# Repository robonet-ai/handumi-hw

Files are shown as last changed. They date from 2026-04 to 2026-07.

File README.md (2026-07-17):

# HandUMI - Hardware

<p align="center">
  
  
  
</p>

<p align="center">
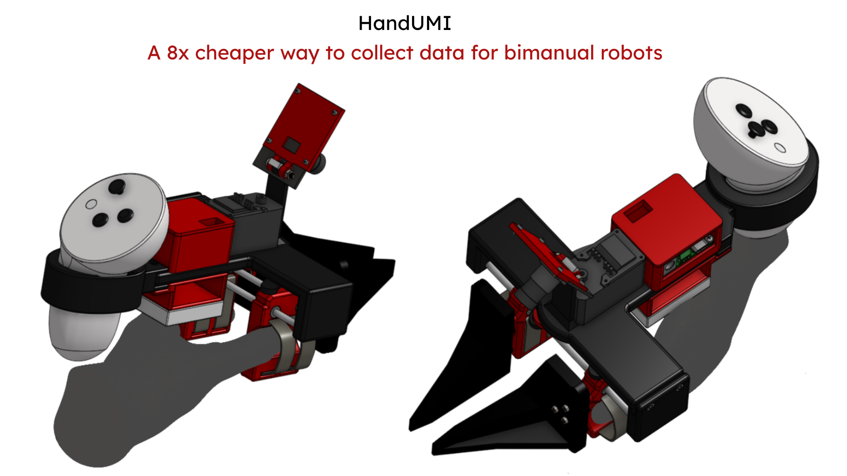
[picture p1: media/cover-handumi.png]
HandUMI - An 8x cheaper way to collect data for bimanual robots
  
</p>

A hand-worn, open-source variant of the Universal Manipulation Interface (UMI)
for collecting bimanual manipulation data without a robot in the loop, designed
for robot arms with parallel grippers. HandUMI mounts on the operator's thumb
and index/middle fingers, opens and closes with a natural pinch, and uses
interchangeable gripper tips to target different parallel-jaw robot grippers.
One unit costs roughly $110 in parts, plus the VR headset of the user's
preference (PICO 4 Ultra or Meta Quest 3).

HandUMI demonstrations are robot-agnostic: collect the data once with the
wearable hardware, then use the [HandUMI software](https://github.com/robonet-ai/handumi-sw)
to retarget it across different bimanual arms with parallel grippers.

## Why Teleoperation Is Not Scalable?

Traditional leader-follower teleoperation is expensive and lab-constrained.

It is expensive because collecting data for bimanual arms requires at least
four robotic arms: two follower arms plus two leader arms, or a VR
headset acting as the leader for both. Even low-cost leader arms like
[GELLO](https://wuphilipp.github.io/gello_site/), which replicate the
follower's kinematics in 3D-printed hardware to cut the leader cost to a few
hundred dollars each, still leave you duplicating both follower arms for
every operator who wants to collect data.

It is lab-constrained because the follower arm has to physically move to
wherever the data needs to be collected. Bolting an arm to a cart and hauling
it between rooms, buildings, or the environments you actually want to collect
data in is slow, heavy, and hard to scale beyond a single fixed setup.

I felt this pain firsthand: the NONHUMAN team and I collected over 2,000
episodes using this method
([link](https://huggingface.co/spaces/lerobot/visualize_dataset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)).

<p align="center">
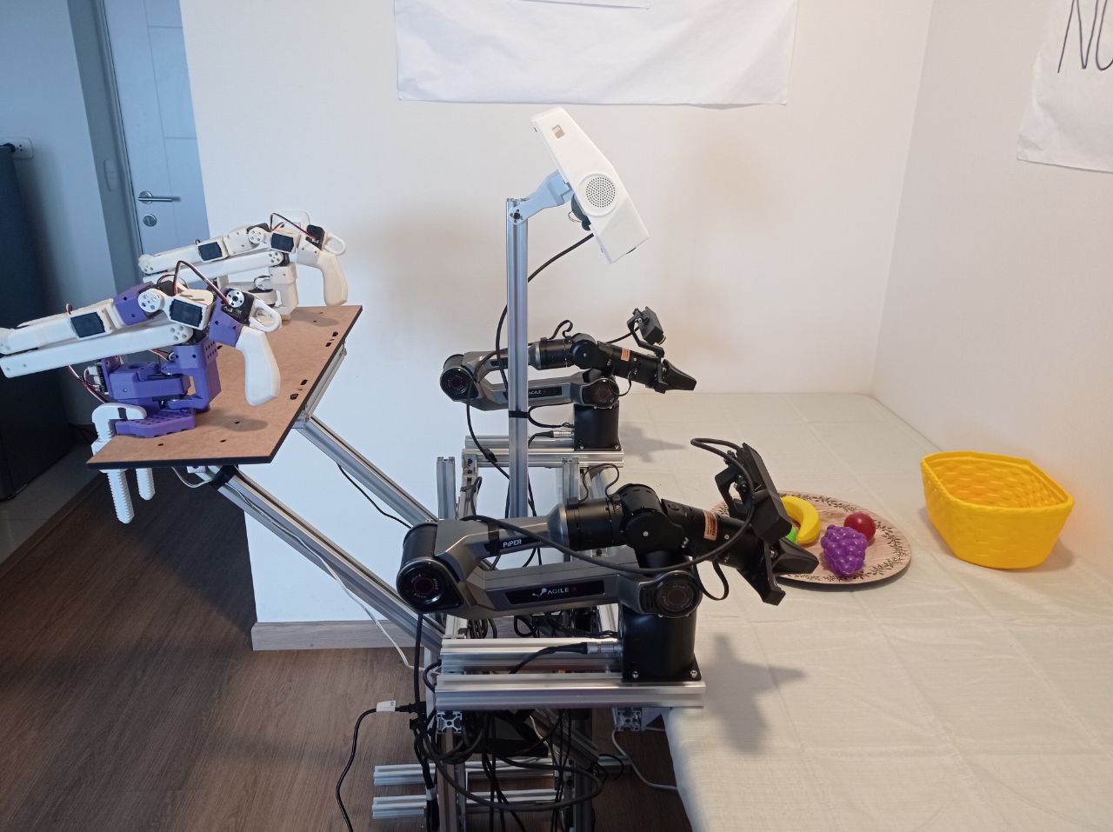
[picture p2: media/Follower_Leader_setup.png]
Classical bimanual leader-follower teleoperation setup
  
</p>

## Why HandUMI

HandUMI removes both the cost and the lab constraint by moving the collection
interface onto the operator's hand instead of onto a robot, the same way the
original UMI removed the lab constraint for its own gripper. This time, that
wearable concept is adapted from [Generalist](https://generalistai.com/)'s
approach and re-targeted at robot arms with parallel-jaw grippers, and it is
open-source and modular: the body, camera mount, servo, and tracker mounting
stay the same across robots, and only the detachable gripper tip changes to
target a new one. Demonstrations can then be captured directly from human
motion, anywhere, without a robot arm at all. Current target tips are AgileX
Piper, ARX X5 2023, Dream Gripper (TRLC), Trossen WidowX AI, and the original
UMI gripper.

Any robot with a comparable parallel-jaw gripper can be supported by designing
and printing a matching tip.

<p align="center">
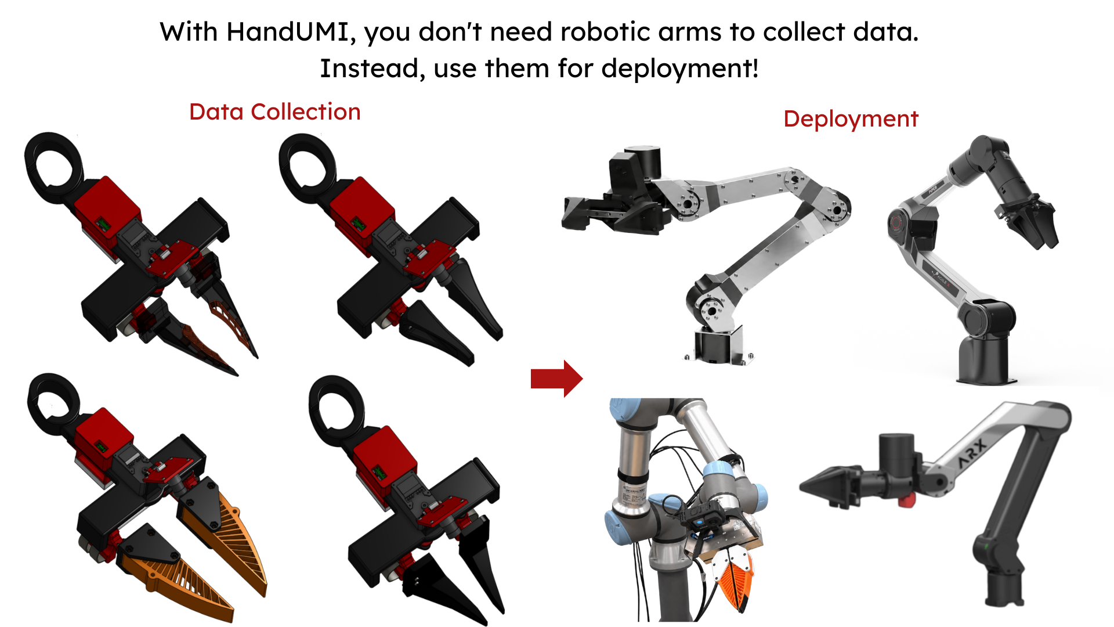
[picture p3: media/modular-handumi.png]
With HandUMI, you don't need robotic arms to collect data. Instead, use them for deployment! Data collection tips vs. deployment arms for AgileX Piper, ARX X5, UR/Dream Gripper, and ARX
  
</p>

## What It Records

Each demonstration records the core signals needed for later deployment:

- SE(3) wrist pose from a VR headset (PICO 4 Ultra or Meta Quest 3) and its
  controllers.
- Gripper width from a Feetech servo encoder.
- Wrist-view video from a small camera mounted on the device.

## Direct Gripper-Width Sensing

Most UMI-style rigs estimate gripper aperture indirectly from fiducials or image
segmentation. HandUMI measures aperture directly with a Feetech servo encoder,
so the recorded width follows the mechanical opening frame by frame.

## Motion Tracking

Pose comes from a VR headset and its two controllers. Depending on the user's
preference, the headset can be a PICO 4 Ultra or a Meta Quest 3. The headset
provides the world frame, while the controllers provide each hand trajectory.
Each HandUMI includes a printed controller support (the
`controller_support` parts in `hardware/STL/left_handumi/` and
`hardware/STL/right_handumi/`) that mounts the controller on the wrist.
This avoids an offline camera SLAM step and keeps the wrist camera focused on
visual observation.

## Wrist-View Camera

The wrist camera provides the observation used during training and deployment.
HandUMI uses the fisheye USB camera listed in the
[Bill of Materials](bom/README.md), a compact UVC module with a wide field of
view.

## Demo

<p align="center">
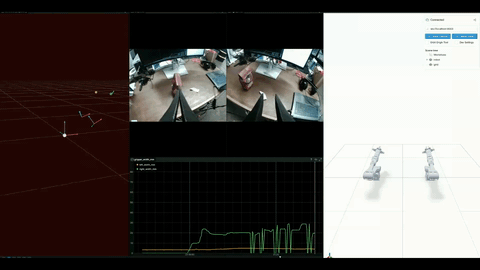
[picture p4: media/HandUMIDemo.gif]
HandUMI data collection demo, showing wrist cameras, gripper-width tracking, and the recorded episode in simulation
  
</p>

### Additional Example

Natural pinch control makes fine-motor tasks tractable that are notoriously
hard to teleoperate with leader-follower puppeteering rigs. Below, an operator
plugs a USB-C cable into a keyboard, a precision insertion task that benefits
directly from direct human dexterity rather than an intermediary robot arm.

<p align="center">
  HandUMI demo: plugging a USB-C cable into a keyboard, a precision task that is hard to teleoperate with leader-follower puppeteering
</p>

## Bill of Materials

The full bill of materials is available in [`bom/README.md`](bom/README.md).
It lists every part needed to build one HandUMI unit — mechanical, structural,
and electronic — with purchase links (Amazon and Alibaba) and per-unit prices.
One unit comes to roughly $110 in parts; a bimanual pair to roughly $221. The
VR headset used for the shared tracking layer is a separate one-time purchase.

## Quick Links

- [Hardware](hardware/README.md)
- [STL files](hardware/STL/)
- [Bill of Materials](bom/README.md)
- [Software](https://github.com/robonet-ai/handumi-sw)
- [Documentation](https://robonet-ai.github.io/handumi-sw/)

## Hand-Fit Design

The finger cradle geometry was designed from a 3D scan of the operator's hand.
That scan is used as a CAD reference surface for the thumb and index/middle
finger rings, and
the same workflow can be repeated to fit another operator.

<p align="center">
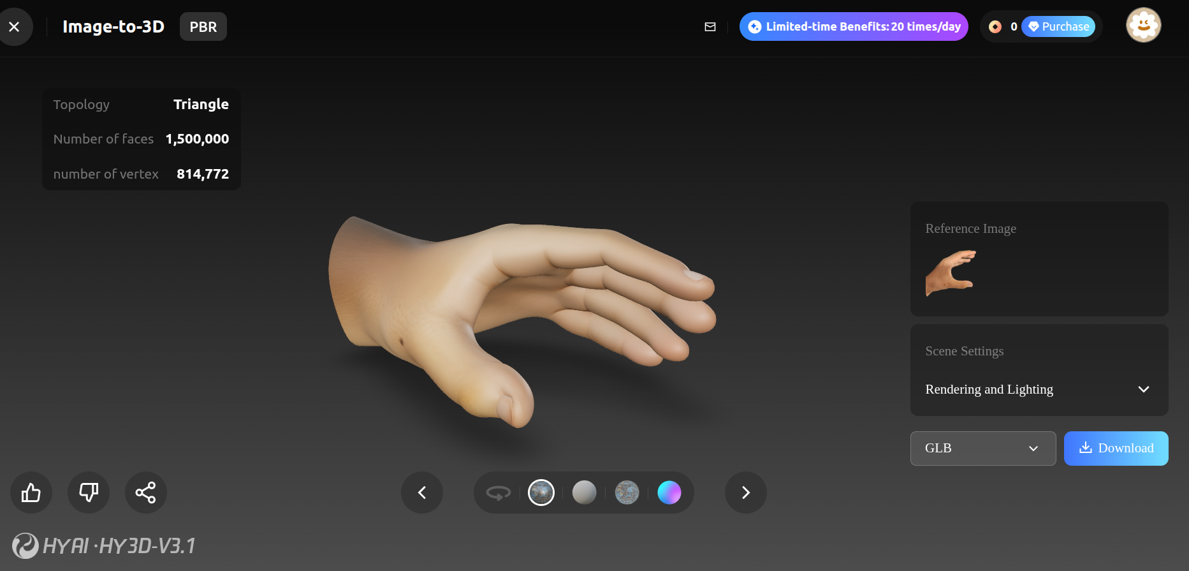
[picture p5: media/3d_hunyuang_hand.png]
3D hand scan used as CAD reference for HandUMI
  
</p>

## References

UMI pioneered in-the-wild data collection without a robot in the loop, and
YUBI brought that idea to a finger-driven V-shaped gripper.
[Generalist](https://generalistai.com/) built a proprietary hand-worn device
for a V-shaped gripper too. HandUMI is the open-source counterpart for robot
arms with parallel-jaw grippers.

- Cheng Chi, Zhenjia Xu, Chuer Pan, Eric Cousineau, Benjamin Burchfiel, Siyuan
  Feng, Russ Tedrake, and Shuran Song. "Universal Manipulation Interface:
  In-The-Wild Robot Teaching Without In-The-Wild Robots." *Robotics: Science
  and Systems (RSS)*, 2024. [https://umi-gripper.github.io/](https://umi-gripper.github.io/)
- Takehiko Ohkawa, Jumpei Arima, Yuki Noguchi, et al. "YUBI: Yielding
  Universal Bidigital Interface for Bimanual Dexterous Manipulation at Scale."
  *arXiv:2606.10244*, 2026. [https://yubi.airoa.io/](https://yubi.airoa.io/)

## Contributing

This project is under active development, and contributions are welcome. Please
read [`CONTRIBUTING.md`](CONTRIBUTING.md) before opening a pull request for
bugs, improvements, documentation, BOM updates, or new gripper tips.

This field still has plenty of unsolved problems, and I'm confident the
open-source community can contribute a great deal toward getting robots to do
tasks we currently think are impossible for them.

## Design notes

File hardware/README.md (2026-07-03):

# Hardware

This folder contains the HandUMI printable hardware.

HandUMI has two hardware configurations that share the same core printed frame:

- Data collector: worn on the hand to record wrist-view video, gripper width,
  and tracker pose.
- Deployment unit: mounted on a robot end-effector with matching camera
  viewpoint and gripper-tip geometry.

## Folder Layout

Printable files live in `STL/`, and editable CAD sources for every part live
in `STEP/`:

```text
STL/
|-- left_handumi/   # Left-hand HandUMI parts
|-- right_handumi/  # Right-hand HandUMI parts
`-- gripper_tips/   # Robot-specific detachable tips, one folder per robot
    |-- AgileX-Piper/
    |-- ARX-X5-2023/
    |-- Dream-Gripper/
    |-- Trossen-WidowXAI/
    `-- UMI-Gripper/

STEP/
|-- left_handumi/   # STEP sources for the left-hand parts
|-- right_handumi/  # STEP sources for the right-hand parts
`-- gripper_tips/   # STEP sources for the tips, for custom adjustments
    |-- AgileX-Piper/
    |-- ARX-X5-2023/
    |-- Dream-Gripper/
    |-- Trossen-WidowXAI/
    `-- UMI-Gripper/
```

## Modular Gripper Tip

HandUMI is modular: the body, camera mount, servo, and tracking mount stay the
same, while the detachable gripper tip changes to match the target robot
gripper.

Currently supported grippers:

- AgileX Piper (`STL/gripper_tips/AgileX-Piper/`)
- ARX X5 2023 (`STL/gripper_tips/ARX-X5-2023/`)
- Dream Gripper TRLC (`STL/gripper_tips/Dream-Gripper/`)
- Trossen WidowX AI (`STL/gripper_tips/Trossen-WidowXAI/`)
- UMI Gripper (`STL/gripper_tips/UMI-Gripper/`)

Any robot with a comparable parallel-jaw gripper can be supported by designing
and printing a matching tip. Start from the STEP sources in
`STEP/gripper_tips/` if you need to adjust a tip or adapt it to a new gripper.
STEP sources for the full left/right bodies are also available in
`STEP/left_handumi/` and `STEP/right_handumi/` for custom modifications
(e.g. refitting the finger cradles to another operator's hand).

## Print Guide

- PLA is the default material for early builds.
- For a left HandUMI, print the complete `STL/left_handumi/` folder.
- For a right HandUMI, print the complete `STL/right_handumi/` folder.
- Depending on your robotic arm with a parallel gripper, print the
  corresponding gripper tips from `STL/gripper_tips/`. If you want to make
  adjustments, modify the STEP sources in `STEP/gripper_tips/` and export your
  own STLs.

Detailed orientation, support, layer height, and infill settings will be added
in a future update.

## Assembly

HandUMI assembly is organized around three modules:

1. Finger-worn body and thumb/index-middle finger cradle.
2. Camera and tracking mounts.
3. Detachable robot-specific gripper tip.

For deployment on a new arm, keep the main body unchanged and swap only the
gripper tip.

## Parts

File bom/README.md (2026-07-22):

# Bill of Materials

## Hardware Required for One HandUMI (Single Unit)

Hardware needed to build one HandUMI unit. Prices use the unit cost from the
linked listing, multiplied by the quantity needed.

### Mechanical & Structural

| Part | Qty Needed | Unit Price | Link | Total (USD)* |
|---|---|---|---|---:|
| PLA Filament (only ~200 g needed per unit) | 0.2 kg | $12.59 / kg | [Amazon](https://www.amazon.com/ELEGOO-Filament-Dimensional-Accuracy-Cardboard/dp/B0BM739JRF) | $2.52 |
| Rolling Bearing | 4 | $13.29 / 20 pcs | [Amazon](https://www.amazon.com/uxcell-3mmx6mmx2-5mm-Shielded-Miniature-Bearing/dp/B075CMRGY6) | $2.66 |
| Linear Bearing | 4 | $7.49 / 4 pcs | [Amazon](https://www.amazon.com/dp/B0FK5PN431?smid=A35BFBRDRD3RNK&ref_=chk_typ_imgToDp&th=1) | $7.49 |
| Axle (135 mm) | 1 rod | $11.99 / 10 pcs | [Amazon](https://www.amazon.com/dp/B08Z8JGZZC) | $1.20 |
| M3 Hardware Kit (750 pcs) | 5 total (1 @ M3x20mm + 2 @ M3x12mm + 2 @ M3x15mm*) | $9.99 / 750 pcs | [Amazon](https://www.amazon.com/Fgruh-750PCS-Assortment-Washers-Assorted/dp/B0RJV3FCBN) | $0.07 |
| Velcro Tape | 4 | $13.99 / 75 pcs | [Walmart](https://www.walmart.com/ip/NavePoint-6-Inch-Hook-and-Loop-Reusable-Strap-Cable-Cord-Wire-Ties-75-Pack-White/180238793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) | $0.75 |
| M2 Hardware Kit (660 pcs) | 16 total (8 screws + 8 nuts) | $7.99 / 660 pcs | [Amazon](https://www.amazon.com/WZHUIDA-Screws-Assortment-M2x4mm-Washers/dp/B0F93XL3WK) | $0.19 |
| **Subtotal** | | | | **$14.88** |

### Electronics

| Part | Qty Needed | Unit Price | Link | Total (USD)* |
|---|---|---|---|---:|
| Fisheye USB Camera | 1 | $56.99 | [Amazon](https://www.amazon.com/Arducam-Computer-Fisheye-Microphone-Windows/dp/B07ZS75KZR) | $56.99 |
| Feetech Servomotor | 1 | $13.89 | [Alibaba](https://www.alibaba.com/product-detail/Top-Seller-Low-Cost-Feetech-STS3215_1600999461525.html) | $13.89 |
| Power Supply | 1 | $10.00 | [Amazon](https://www.amazon.com/Facmogu-Switching-Transformer-Compatible-5-5x2-1mm/dp/B087LY41PV) | $10.00 |
| Feetech Servo Controller | 1 | $10.60 | [Amazon](https://www.amazon.com/Waveshare-Integrates-Control-Circuit-Supports/dp/B0CTMM4LWK) | $10.60 |
| USB-C Cable | 1 | $7.00 / 2 pcs | [Amazon](https://www.amazon.com/Charging-etguuds-Charger-Braided-Compatible/dp/B0B8NWLLW2) | $3.50 |
| **Subtotal** | | | | **$94.98** |

### Total

| | |
|---|---:|
| **GRAND TOTAL (approx.)** | **$109.86** |
| If building a pair (2 units) | $219.72 |

\*Unit Price reflects the real per-unit cost from the linked listing (e.g. pack
price ÷ pack quantity); Total = Unit Price × Qty Needed. Prices are early
reference estimates and may vary with shipping, region, and availability.

**Note:** this BOM does not include the VR headset (e.g. PICO 4 Ultra /
Meta Quest) used for the shared tracking layer. That is a separate, one-time
purchase, not duplicated per HandUMI unit.

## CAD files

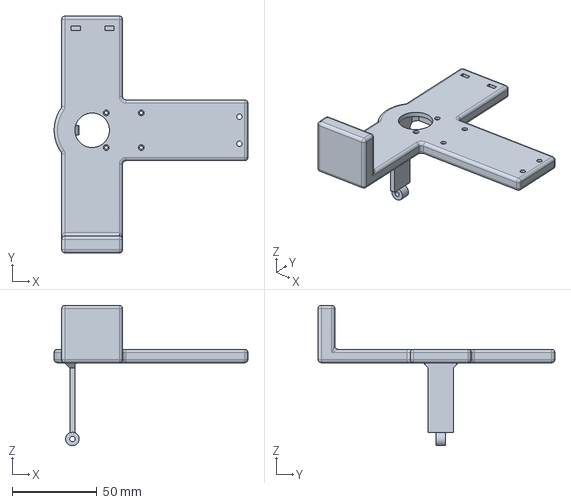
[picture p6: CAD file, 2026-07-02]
hardware/STEP/right_handumi/fisheye_camera_main_support.step
114.5 x 140.0 x 83.0 mm

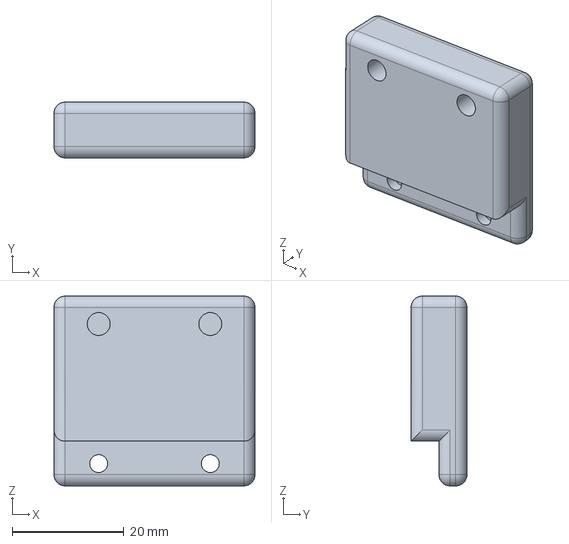
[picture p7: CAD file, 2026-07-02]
hardware/STEP/left_handumi/main_support_cover_plate.step
36.0 x 10.0 x 34.0 mm

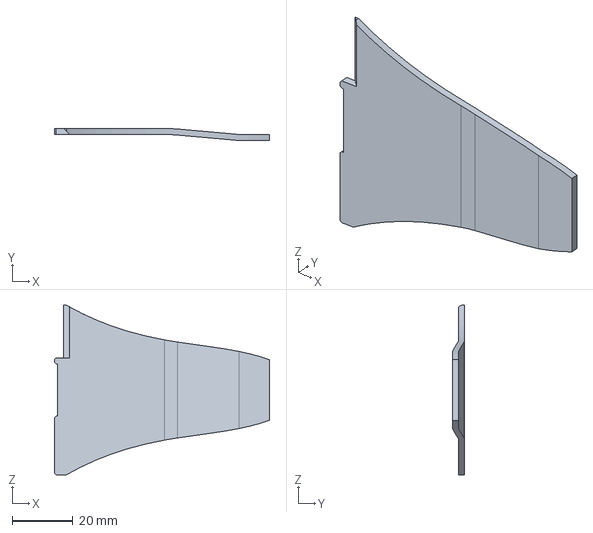
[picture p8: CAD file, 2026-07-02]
hardware/STEP/gripper_tips/AgileX-Piper/Piper-LEFT-Gripper-Pad.step
71.0 x 4.00 x 56.0 mm

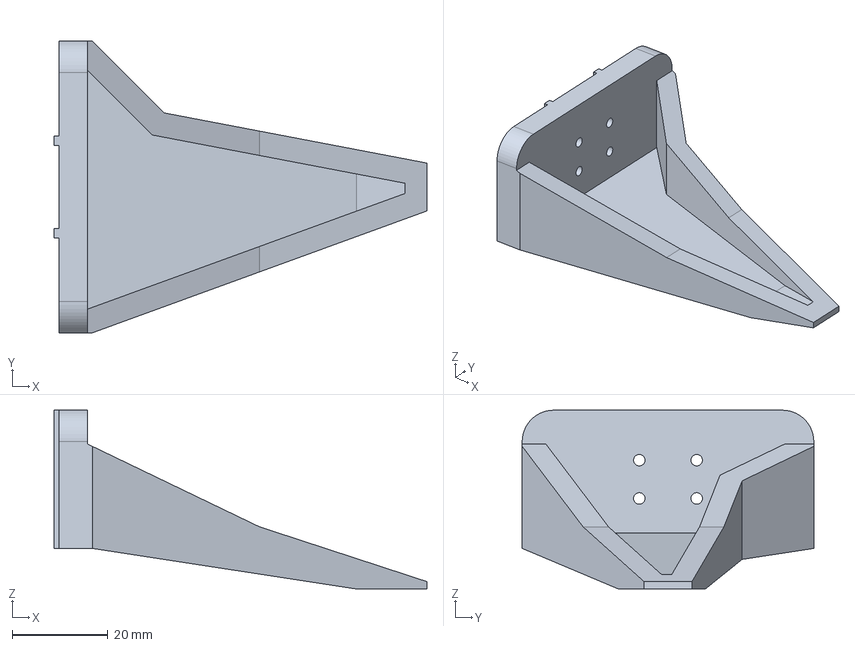
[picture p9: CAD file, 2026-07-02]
hardware/STEP/gripper_tips/ARX-X5-2023/ARX-X5-2023-RIGHT-Gripper.step
78.0 x 61.0 x 37.4 mm

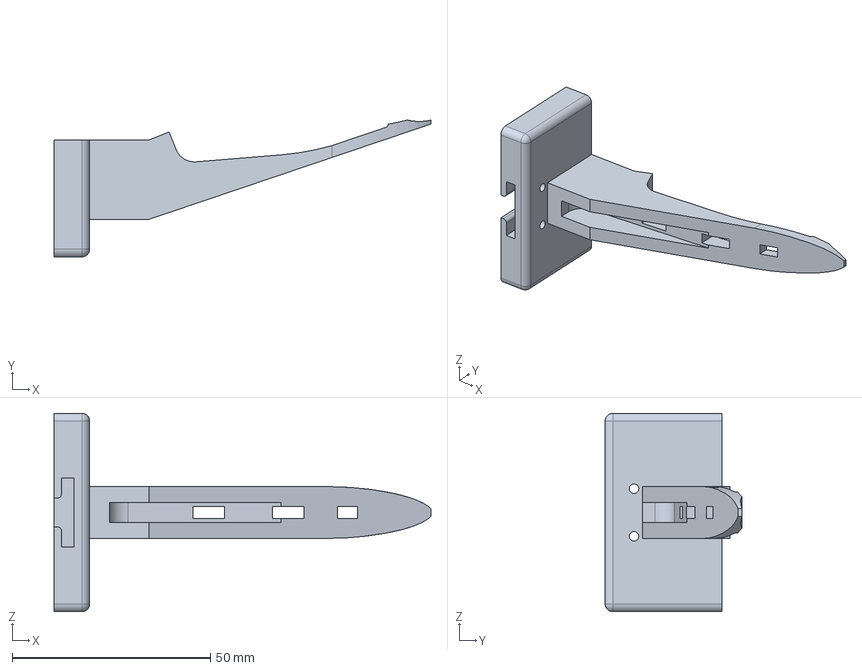
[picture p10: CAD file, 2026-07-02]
hardware/STEP/gripper_tips/Dream-Gripper/TRLC-Dream-Gripper-LEFT-Backbone.step
95.0 x 34.5 x 50.0 mm

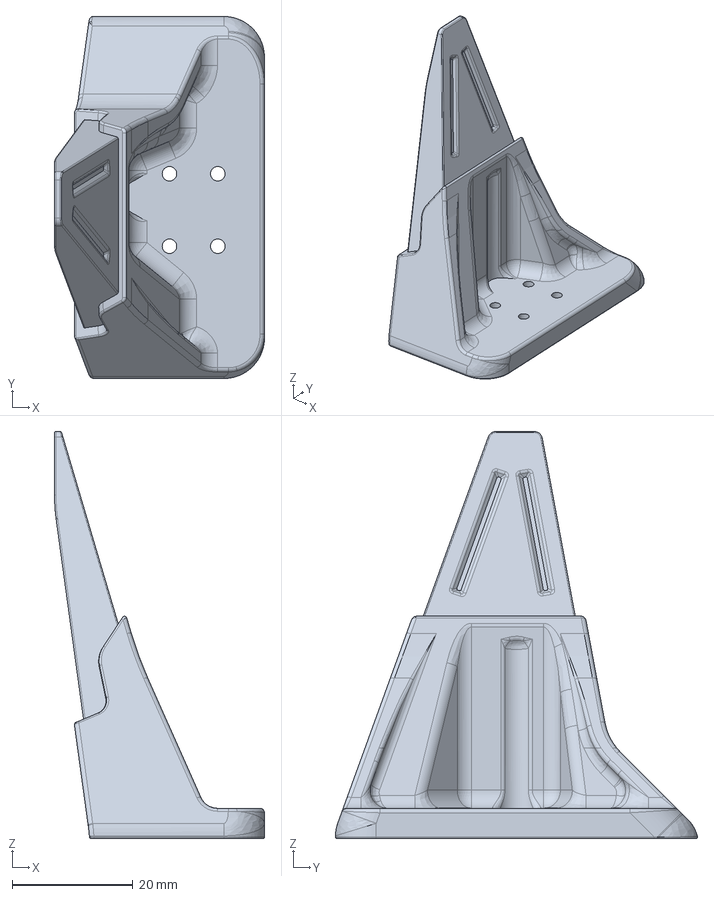
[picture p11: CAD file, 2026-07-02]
hardware/STEP/gripper_tips/Trossen-WidowXAI/WXAI-LEFT-Gripper-backbone.step
34.8 x 59.9 x 67.4 mm

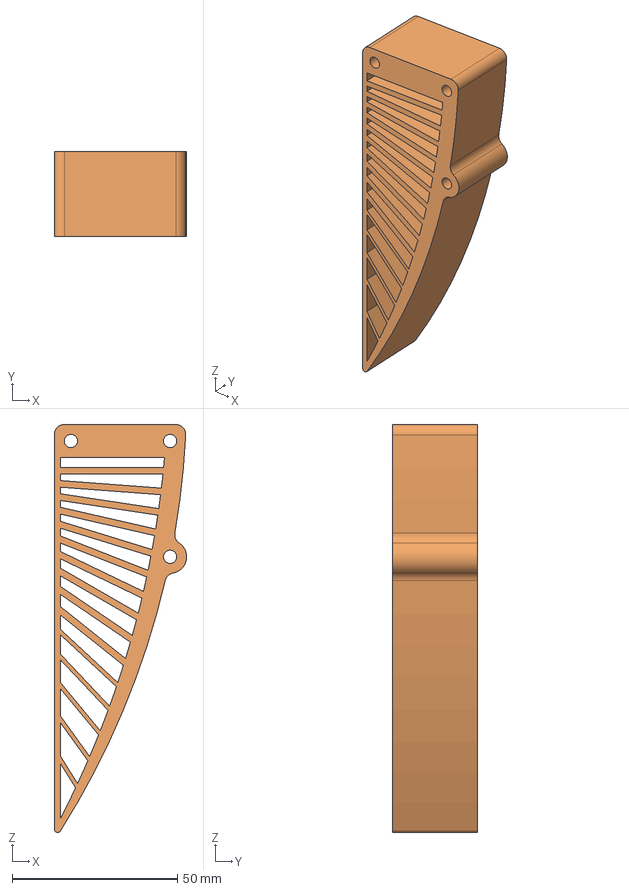
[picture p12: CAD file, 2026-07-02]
hardware/STEP/gripper_tips/UMI-Gripper/UMI-RIGHT-Soft-Gripper-Finger.step
40.0 x 25.8 x 123.4 mm

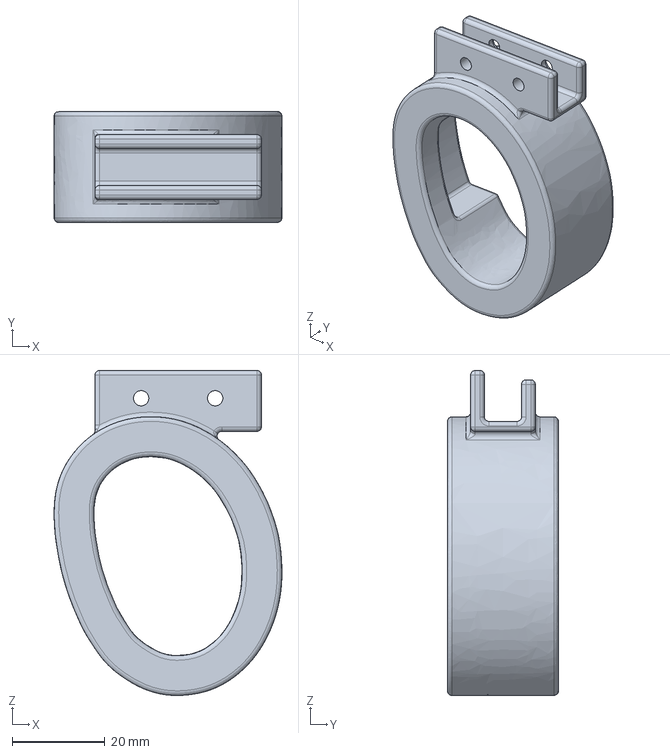
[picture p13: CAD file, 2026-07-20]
hardware/STEP/left_handumi/left_controller_support.step
49.2 x 24.0 x 70.2 mm

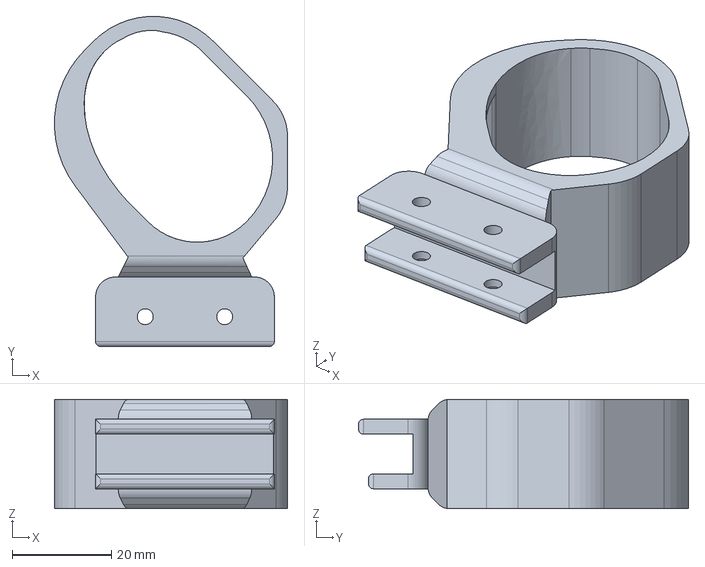
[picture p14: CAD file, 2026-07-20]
hardware/STEP/right_handumi/right_controller_support.step
46.9 x 66.5 x 22.0 mm

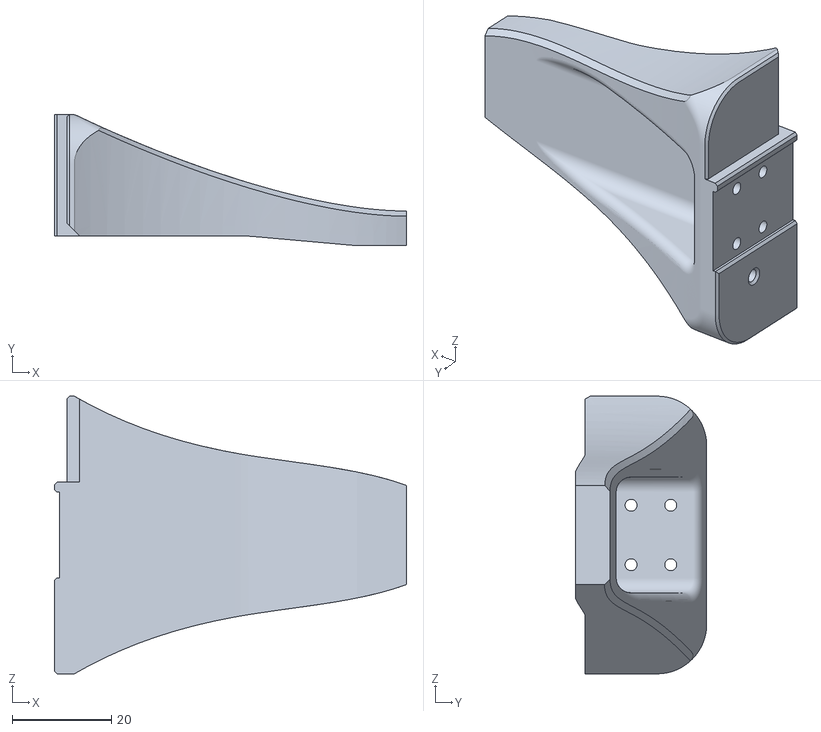
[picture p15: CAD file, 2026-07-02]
hardware/STL/gripper_tips/AgileX-Piper/Agile-X-Piper-LEFT-Gripper.stl
71.0 x 26.5 x 56.0

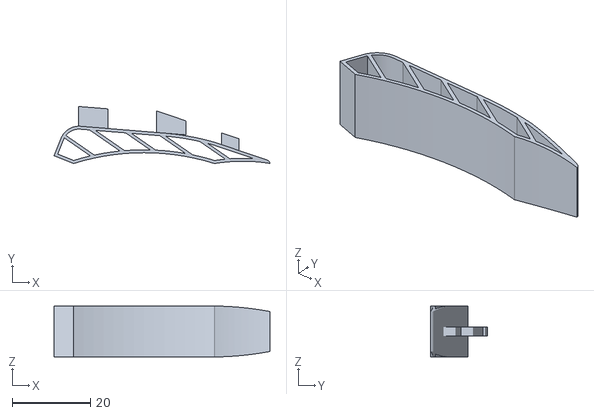
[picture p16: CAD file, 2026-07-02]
hardware/STL/gripper_tips/Dream-Gripper/Dream-Gripper-TRLC-Insert-TPU.stl
55.2 x 14.6 x 13.0

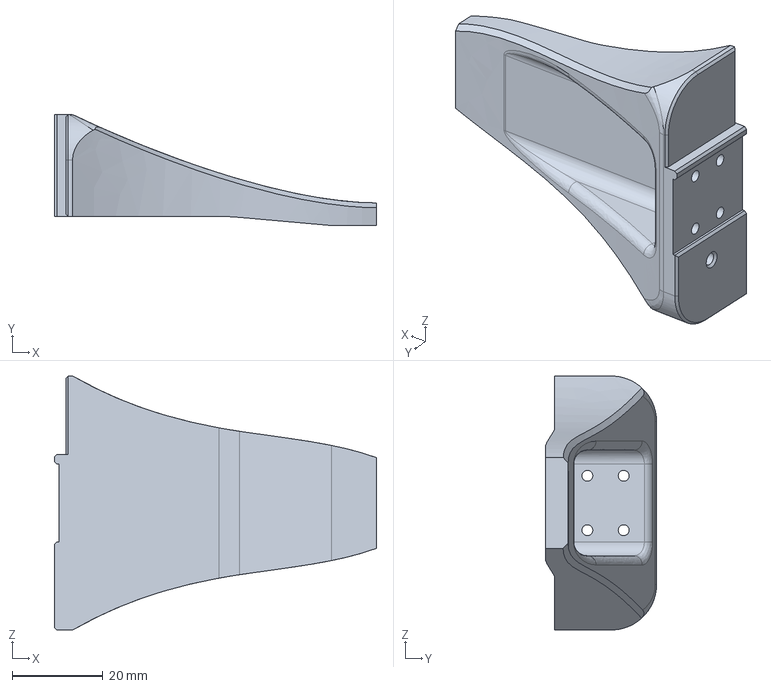
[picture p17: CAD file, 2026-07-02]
hardware/STEP/gripper_tips/AgileX-Piper/Piper-LEFT-Gripper-Jaw.step
71.0 x 24.5 x 56.0 mm

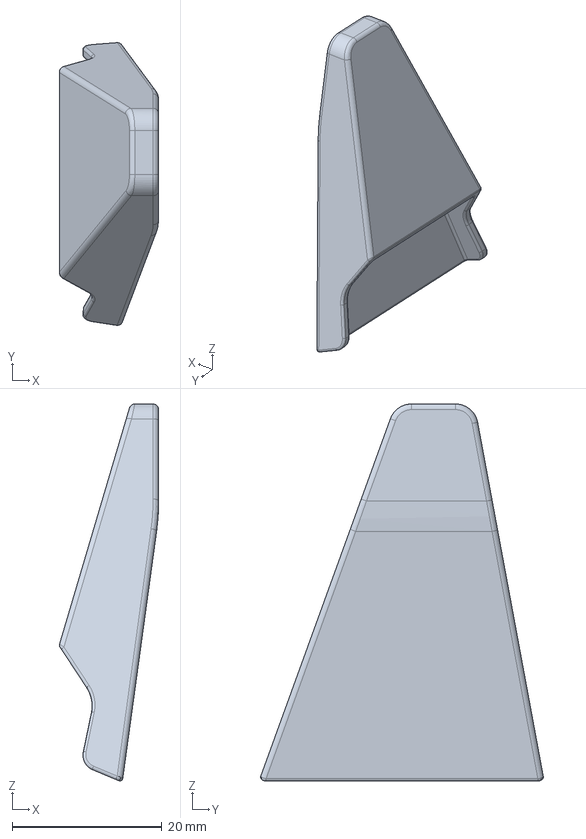
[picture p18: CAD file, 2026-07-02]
hardware/STEP/gripper_tips/Trossen-WidowXAI/WXAI-RIGHT-Gripper-sock.step
13.3 x 37.8 x 50.4 mm

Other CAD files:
hardware/STL/gripper_tips/UMI-Gripper/UMI-Soft-Gripper-Finger.stl
hardware/STEP/gripper_tips/ARX-X5-2023/ARX-X5-2023-LEFT-Gripper.step
hardware/STEP/gripper_tips/AgileX-Piper/Piper-RIGHT-Gripper-Jaw.step
hardware/STEP/gripper_tips/AgileX-Piper/Piper-RIGHT-Gripper-Pad.step
hardware/STEP/gripper_tips/Dream-Gripper/TRLC-Dream-Gripper-LEFT-Insert-TPU.step
hardware/STEP/gripper_tips/Dream-Gripper/TRLC-Dream-Gripper-RIGHT-Insert-TPU.step
hardware/STEP/gripper_tips/Trossen-WidowXAI/WXAI-LEFT-Gripper-sock.step
hardware/STEP/gripper_tips/Trossen-WidowXAI/WXAI-RIGHT-Gripper-backbone.step
hardware/STEP/gripper_tips/UMI-Gripper/UMI-LEFT-Finger-Holder.step
hardware/STEP/gripper_tips/UMI-Gripper/UMI-RIGHT-Finger-Holder.step
hardware/STEP/left_handumi/camera_mount.step
hardware/STEP/left_handumi/connecting_link_1.step
hardware/STEP/left_handumi/connecting_link_2.step
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

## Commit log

2026-07-02 Grippers STL: Piper, ARX X5, Dream Grippers
    [ARX-X5-2023-LEFT-Gripper.stl, ARX-X5-2023-RIGHT-Gripper.stl, Agile-X-Piper-LEFT-Gripper.stl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]
2026-07-02 Grippers STEP: Piper, ARX, Dream Gripper
    [ARX-X5-2023-LEFT-Gripper.step, ARX-X5-2023-LEFT-Gripper.stl, ARX-X5-2023-RIGHT-Gripper.step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]
2026-07-02 left handumi STLs added
    [camera_mount.stl, connecting_link_1.stl, connecting_link_2.stl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]
2026-07-02 right handumi STLs added
    [camera_mount.stl, connecting_link_1.stl, connecting_link_2.stl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]
2026-07-02 Gripper STL & STEP: Trossen WidowX AI
    [WXAI-LEFT-Gripper-backbone.step, WXAI-LEFT-Gripper-sock.step, WXAI-LEFT-Gripper-sock.stl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]
2026-07-02 Update BOM with per-unit costs and links, align READMEs with camera, headset, and finger details
2026-07-02 Gripper STEP & STL: UMI Gripper
    [UMI-LEFT-Finger-Holder.step, UMI-LEFT-Finger-Holder.stl, UMI-RIGHT-Finger-Holder.step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]
2026-07-02 Duplicates added for better usability
    [TRLC-Dream-Gripper-LEFT-Backbone.step, TRLC-Dream-Gripper-LEFT-Insert-TPU.step, TRLC-Dream-Gripper-RIGHT-Backbone.step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]
2026-07-02 STEP Left HandUMI, Left Controller Support Updated
    [camera_mount.step, connecting_link_1.step, connecting_link_2.step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]
2026-07-02 STEP Right HandUMI, Right Controller Support Updated
    [camera_mount.step, connecting_link_1.step, connecting_link_2.step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]
2026-07-03 README and gif updated
    [WXAI-LEFT-Gripper-backbone.step, WXAI-LEFT-Gripper-sock.step, WXAI-RIGHT-Gripper-backbone.step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]
2026-07-15 Linear bearing link updated
2026-07-15 Fix link formatting for Linear Bearing in README
2026-07-18 left and right links updated
    [left_index_middle_finger_link.stl, left_thumb_link.stl, right_index_middle_finger_link.stl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]
2026-07-20 controller support updated
    [left_controller_support.step, right_controller_support.step]
2026-07-22 Update STL files considering 3D printing tolerance
    [fisheye_camera_main_support.stl, left_index_middle_finger_link.stl, left_thumb_link.stl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]
2026-07-22 docs(bom): update Velcro supplier and recalculate totals
2026-07-22 hand support base issue with the new controller support fixed
    [hand_support_base.stl]
2026-07-22 feat(hardware): update left and right hand support bases
    [hand_support_base.stl]

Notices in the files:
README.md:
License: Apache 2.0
